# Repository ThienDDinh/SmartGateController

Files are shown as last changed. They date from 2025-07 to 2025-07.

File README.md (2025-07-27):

# Connectivity Interface Module

**A Smart Gate Add-On for the Letron SL3000 Sliding Gate Opener**

The Connectivity Interface Module (CIM) is an ESP32-based add-on designed to integrate seamlessly with the Letron SL3000 sliding gate opener. It interfaces directly with the gate’s existing RF control infrastructure—the same system used by the original remotes—allowing smart control without modifying the base system. CIM adds Home Assistant integration, optional state monitoring, and remote triggering using standard hobbyist tools. All connections are made via screw terminals for a fully non-invasive, easily reversible install that preserves full compatibility with manufacturer remotes.

---

## 🚪 Features

* Home Assistant integration using **ESPHome**, a framework for controlling ESP32 devices over Wi-Fi
* Remote gate triggering via either ESPHome commands or the original Letron RF remotes
* Screw terminal connections for simple, fully reversible install
* Optional limit switch input for gate open/close state sensing
* USB-C port for easy firmware flashing and debugging, with onboard bootloader button

---

## 🧠 System Overview

The Connectivity Interface Module (CIM) physically interfaces with the Letron SL3000 main control board at the same 6-pin header where the original RF receiver connects. It sits in-line using a custom interposer PCB, allowing the original RF receiver to remain in place while the CIM takes over control of the gate trigger input.

The Letron controller expects a 5 V active-low signal on its trigger input to initiate a gate cycle. There are two methods of generating this signal. The CIM will generate this signal in response to a Home Assistant command received via ESPHome, and the RF receiver will still be able to generate this signal as normal. The logic for whether the gate opens or closes remains entirely within the Letron controller.

The CIM draws power from the same 12 V supply provided to the RF receiver. An onboard voltage regulator steps this down to 3.3 V for the ESP32 and associated circuitry. No external power supply is needed.

---

## 4. Getting Started

### 4.1 Prerequisites

* A running Home Assistant server/instance
* ESPHome installed on your computer (for compiling and flashing firmware)
* USB-C cable for firmware flashing
* PH1 screwdriver to remove the Letron enclosure
* Flat-blade (slotted) screwdriver for the screw terminals

### 4.2 Firmware Flashing (Pre-Install)

1. Install ESPHome on your workstation or in Home Assistant.
2. In the repo’s `/firmware/` folder, copy `example.yaml` → `gate-controller.yaml`.
3. Edit `gate-controller.yaml`:

   * Set your Wi-Fi SSID and password
   * Configure a static IP (matching your router’s subnet, mask, gateway, DNS)
4. **Hold the onboard bootloader button down**, then connect the CIM via USB-C.
5. Run:

   ```bash
   esphome run gate-controller.yaml
   ```
6. After flashing, unplug USB-C and power-cycle the board (no button press). Confirm your router has assigned or reserved the specified IP.

### 4.3 Home Assistant Integration

1. In HA, go to **Settings → Devices & Services**.
2. ESPHome should appear under “Discovered Devices.”
3. Click **Configure**.
4. **Add your device**.
5. Test software connectivity by sending a gate trigger command from Home Assistant while the CIM is still USB-C connected—watch the ESPHome logs to confirm the ESP32 received and acted on the command.

### 4.4 Hardware Setup

1. **Power off the gate controller**

   * Remove the battery connection **and** switch off AC power to the onboard charger.
2. **Open the enclosure**

   * Use a PH1 screwdriver to remove the Letron SL3000 cover.
3. **Install the CIM interposer**

   * Unplug the original RF receiver from the 6-pin header on the Letron board.
   * Plug the CIM interposer PCB into that header using the 6-way screw terminal (MAIN_CONN)
   * Reconnect the RF receiver to the CIM's 6-pin header (RF_CONN)
   * Jump the **CL** and **OL** limit-switch terminals from the Letron controller to the CIM's 2-way screw terminal (LSW_CONN)

4. **Restore power**

   * Re-plug the 12 V feed and switch AC power back on.

---

## 5. Known Issues / Prototype Notes

> **Prototype status:** Only v0.4 was assembled. Design corrections are captured in v0.5 but will not be produced and tested.

* **Issue – Floating RF_OUT line**
  Measured RF_OUT at \~5 V idle—but it’s pulled high by the Letron controller, not driven by the RF board. When inactive it drifted to \~0.8 V, which the CIM’s v0.4 divider didn’t recognize as HIGH.

  **Workaround**
  Added a 10 kΩ pull-up to 5 V before the divider so the ESP32 sees a solid HIGH until the RF receiver pulls the line low. Tie RF_OUT and CIM_OUT together using a jumper wire connected to the screw terminals.

   **Design update**  
  Eliminated that pull-up, and merged RF_OUT and CIM_OUT onto the same active-LOW trigger line (OUT). Now the RF receiver can still drive the gate directly when the CIM is inactive, and the CIM simply monitors that shared line to detect any trigger (whether from itself or RF). The line remains pulled up to 5 V by the Letron controller, and the CIM uses its divider to read it.

* **Issue – Buck converter EN-pin logic**
  The 5 V buck converter’s EN pin must be LOW to enable output but was wired HIGH, so it stayed off.

  **Workaround**
  Cut the EN leg on the buck IC to force it LOW, enabling the converter.

  **Design update**
  Tie EN to GND so the converter is always enabled.

---

## 📂 Hardware

* `/hardware/v0.4/` – As-built v0.4 prototype files (do not produce):

  * `schematic.pdf` – PDF export for reference
  * `gerber/` – Gerber files for board fabrication
  * `bom.csv` – Bill of Materials

* `/hardware/v0.5/` – Improved v0.5 prototype files (not yet tested):

  * `schematic.pdf` – PDF export for reference
  * `gerber/` – Gerber files for board fabrication
  * `bom.csv` – Bill of Materials

## 📂 Firmware

* `/firmware/` – ESPHome configurations and examples:

  * `gate-controller.yaml` – Primary firmware for v0.4/v0.5 hardware

## ⚖️ License

[MIT License](LICENSE)

---

## 🤝 Credits

* **Developer:** ThienDDinh
* **Original System:** Letron SL3000 sliding gate opener

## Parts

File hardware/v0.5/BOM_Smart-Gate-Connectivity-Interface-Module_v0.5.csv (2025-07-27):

ID | Name | Designator | Footprint | Quantity | Manufacturer Part | Manufacturer | Supplier | Supplier Part | Price
1 | A254UP-ZD06P | RF_CONN | HDR-TH_6P-P2.54-V-M | 1 | A254UP-ZD06P | BXCONN(宝讯) | LCSC | C41413835 | 0.035
2 | 10kΩ | R4,R13 | R0603 | 2 | 0603WAF1002T5E | UNI-ROYAL(厚声) | LCSC | C25804 | 0.001
3 | 470uF | C1 | CAP-SMD_BD8.0-L8.3-W8.3-FD | 1 | RST470UF25V032 | KNSCHA(科尼盛) | LCSC | C4747956 | 0.074
4 | 1uF | C2,C4,C5,C6,C9 | C0603 | 5 | CL10A105KB8NNNC | SAMSUNG(三星) | LCSC | C15849 | 0.005
5 | 0.1uF | C7 | C0603 | 1 | CC0603KRX7R9BB104 | YAGEO(国巨) | LCSC | C14663 | 0.003
6 | SS14 | D3,D2 | SMA_L4.2-W2.6-LS5.0-RD_1 | 2 | SS14 | MDD(辰达半导体) | LCSC | C2480 | 0.016
7 | USBLC6-2SC6 | D4 | SOT-23-6_L2.9-W1.6-P0.95-LS2.8-BL | 1 | USBLC6-2SC6 | TECH PUBLIC(台舟) | LCSC | C2827654 | 0.038
8 | 68uH | L1 | IND-SMD_L4.5-W4.0_GCD43-XX | 1 | CY43-68UH | SHOU HAN(首韩) | LCSC | C2929423 | 0.035
9 | 2N3904U 1A | Q1 | SOT-89-3_L4.5-W2.5-P1.50-LS4.2-BR | 1 | 2N3904U | CBI(创基) | LCSC | C2928256 | 0.026
10 | 5.6kΩ | R1 | R0603 | 1 | 0603WAF5601T5E | UNI-ROYAL(厚声) | LCSC | C23189 | 0.001
11 | 1kΩ | R3 | R0603 | 1 | 0603WAF1001T5E | UNI-ROYAL(厚声) | LCSC | C21190 | 0.001
12 | 5.1kΩ | R5,R6 | R0603 | 2 | 0603WAF5101T5E | UNI-ROYAL(厚声) | LCSC | C23186 | 0.001
13 | ESP32-C3-MINI-1-N4 | U1 | WIFIM-SMD_ESP32-C3-MINI-1 | 1 | ESP32-C3-MINI-1-N4 | ESPRESSIF(乐鑫) | LCSC | C2838502 | 3.005
14 | XL1509-5.0E1 | U2 | SOIC-8_L5.0-W4.0-P1.27-LS6.0-BL | 1 | XL1509-5.0E1 | XLSEMI(芯龙) | LCSC | C61063 | 0.227
15 | AP2112K-3.3TRG1 | U3 | SOT-25-5_L2.9-W1.6-P0.95-LS2.8-BL | 1 | AP2112K-3.3TRG1 | DIODES(美台) | LCSC | C51118 | 0.109
16 | UC09-0B16F00P11 | USB1 | USB-C_UC09-0B16F00P11 | 1 | UC09-0B16F00P11 | BXCONN(宝讯) | LCSC | C36936538 | 0.113
17 | 100uF | C3,C8 | CASE-B_3528 | 2 | TAJB107M010RNJ | Kyocera AVX | LCSC | C7196 | 0.262
18 | 1N5820G | D1 | DO-201AD_BD5.3-L8.4-P12.50-D1.4-RD | 1 | 1N5820G | onsemi(安森美) | LCSC | C95400 | 0.587
19 | WJ124-3.81-6P | MAIN_CONN | CONN-TH_6P-P3.81_WJ124-3.81-6P | 1 | WJ124-3.81-6P | KANGNEX(康奈克斯电气) | LCSC | C69810 | 0.417
20 | DB301V-3.81-2P-GN | LSW_CONN | CONN-TH_DB301V-3.81-2P-GN | 1 | DB301V-3.81-2P-GN-S | DORABO(地博电气) | LCSC | C2826458 | 0.122
21 | 2.2kΩ | R7,R9 | R0603 | 2 | 0603WAF2201T5E | UNI-ROYAL(厚声) | LCSC | C4190 | 0.001
22 | 4.7kΩ | R8,R10 | R0603 | 2 | 0603WAF4701T5E | UNI-ROYAL(厚声) | LCSC | C23162 | 0.001
23 | 100Ω | R11,R12 | R0603 | 2 | 0603WAF1000T5E | UNI-ROYAL(厚声) | LCSC | C22775 | 0.001
24 | K2-1157SP-I4SW-04 | SW1 | SW-SMD_4P-L6.2-W6.2-P4.50-LS8.6 | 1 | K2-1157SP-I4SW-01 | 韩国韩荣 | LCSC | C2909692 | 0.094

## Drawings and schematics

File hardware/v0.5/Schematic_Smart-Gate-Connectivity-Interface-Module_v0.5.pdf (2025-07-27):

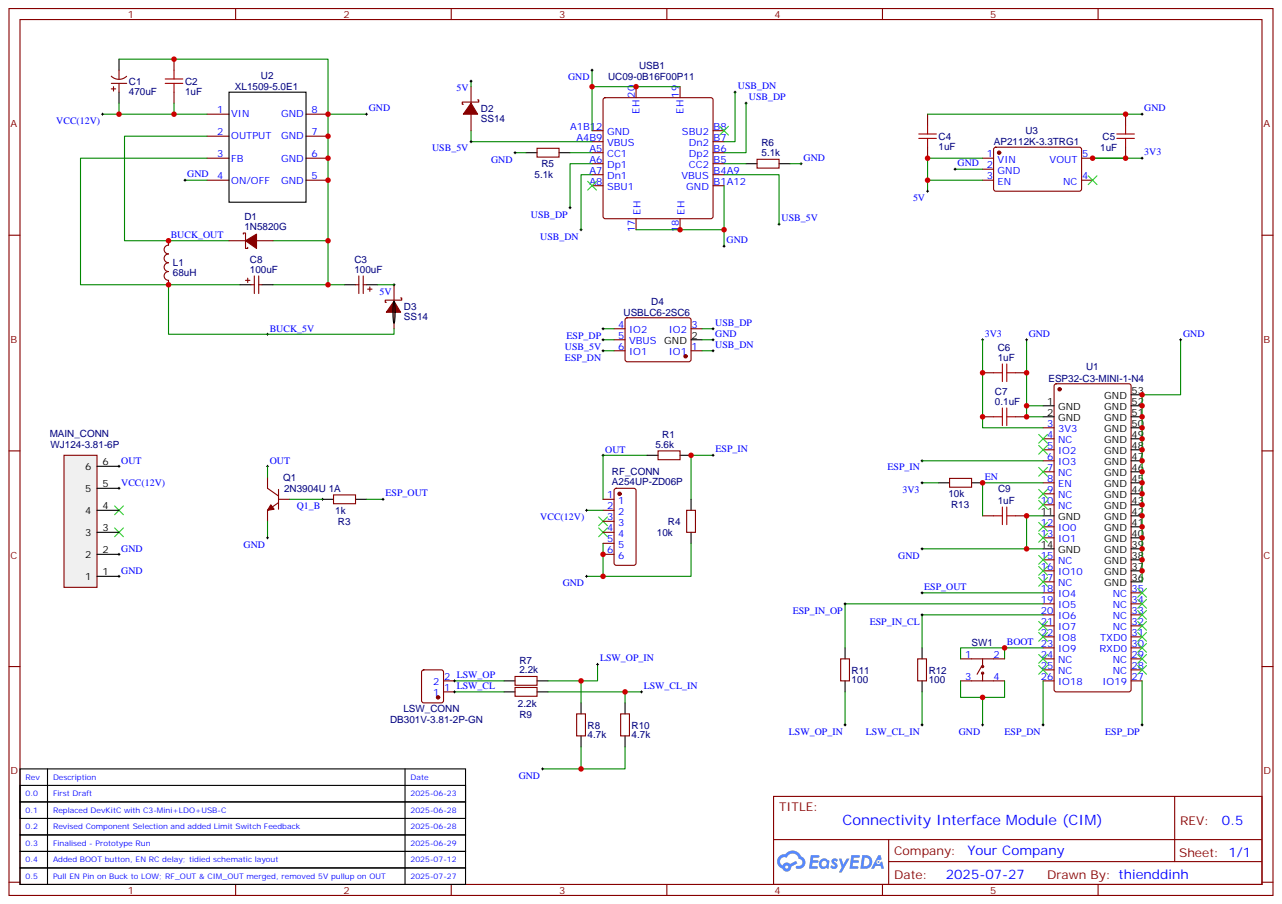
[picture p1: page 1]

Revised Component Selection and added Limit Switch Feedback

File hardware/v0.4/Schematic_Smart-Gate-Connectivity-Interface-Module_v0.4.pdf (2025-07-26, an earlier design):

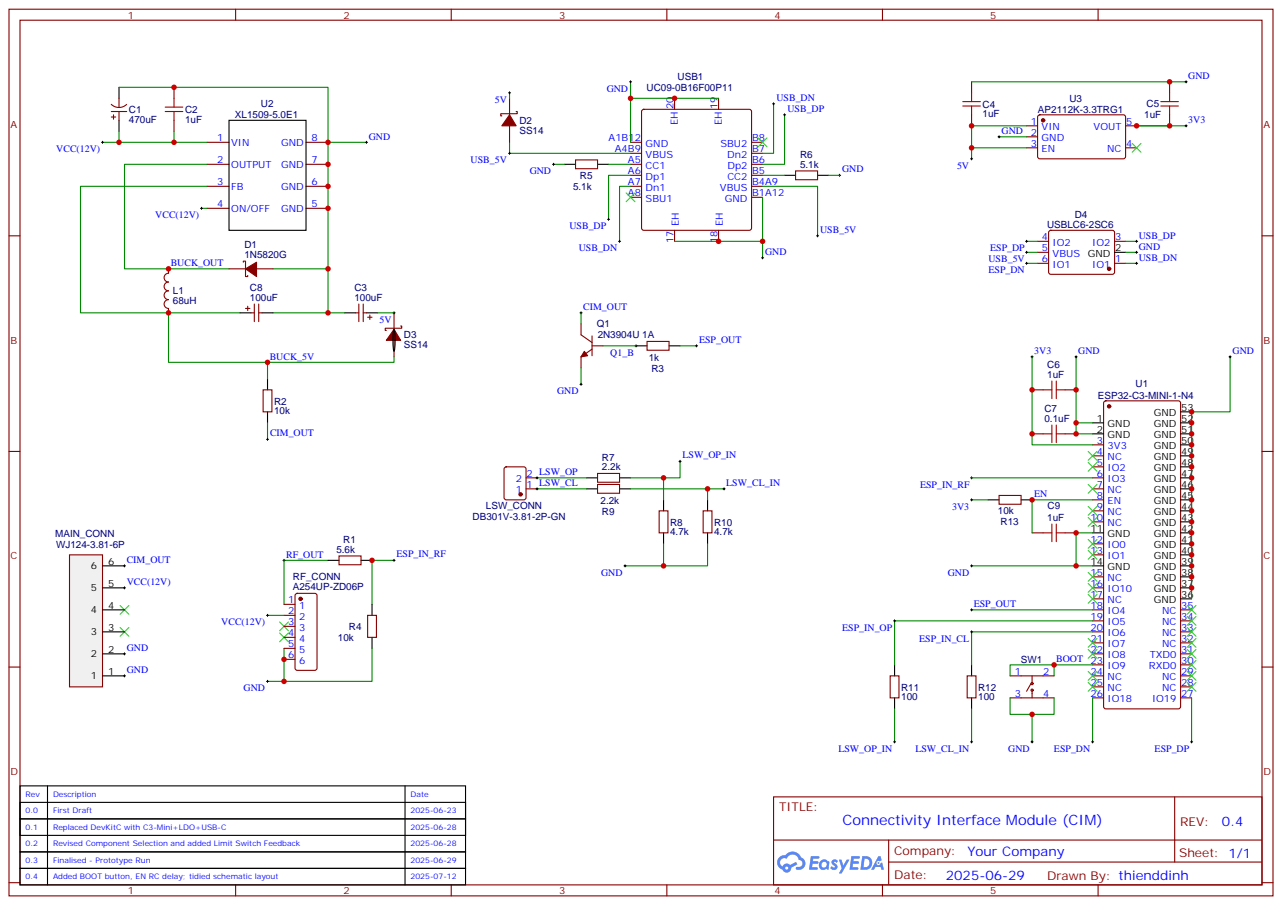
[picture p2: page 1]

Revised Component Selection and added Limit Switch Feedback

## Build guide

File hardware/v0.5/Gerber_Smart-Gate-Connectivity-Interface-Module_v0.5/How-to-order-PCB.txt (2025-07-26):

How to Order PCB

Please refer to:
https://docs.easyeda.com/en/PCB/Order-PCB

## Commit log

2025-07-26 Initial commit: add README, LICENSE, hardware files
    [gate-controller.yaml]
2025-07-26 Add hardware files, fimrware files, and update README
    [BOM_Smart-Gate-Connectivity-Interface-Module_v0.4.csv, BOM_Smart-Gate-Connectivity-Interface-Module_v0.5.csv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]
2025-07-27 Revision to v0.5 hardware, Update firmware to v2.0.0, update README
    [BOM_Smart-Gate-Connectivity-Interface-Module_v0.5.csv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]
